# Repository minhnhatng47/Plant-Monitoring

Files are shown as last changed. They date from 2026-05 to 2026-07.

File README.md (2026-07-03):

# Plant-Monitoring-CPS

## Giới thiệu

**Plant-Monitoring-CPS** là mô hình hệ thống Cyber-Physical System (CPS) ứng dụng trong giám sát và chăm sóc cây trồng. Hệ thống tích hợp các công nghệ IoT, MQTT, Edge AI, cơ sở dữ liệu thời gian thực và mô hình Digital Twin trên Unity nhằm thu thập dữ liệu môi trường, xử lý tại biên, điều khiển thiết bị và trực quan hóa trạng thái cây trồng theo thời gian thực.

Đề tài được xây dựng cho mô hình chăm sóc rau cải mầm (*Brassica juncea*) trong môi trường thử nghiệm. Hệ thống có khả năng đo các thông số như nhiệt độ, độ ẩm không khí, độ ẩm đất và cường độ ánh sáng. Dữ liệu được gửi từ ESP32 về Raspberry Pi thông qua MQTT, sau đó được xử lý, lưu trữ, hiển thị trên Web Dashboard và đồng bộ với mô hình Digital Twin trong Unity.

## Mục tiêu dự án

Dự án hướng đến việc xây dựng một mô hình CPS hoàn chỉnh cho chăm sóc cây trồng thông minh với các mục tiêu chính:

- Thu thập dữ liệu môi trường từ các cảm biến.
- Truyền dữ liệu giữa ESP32, Raspberry Pi, Web Dashboard và Unity thông qua MQTT.
- Lưu trữ dữ liệu cảm biến theo thời gian thực bằng InfluxDB.
- Xử lý dữ liệu tại biên bằng Raspberry Pi.
- Ứng dụng mô hình Machine Learning để hỗ trợ quyết định bật/tắt bơm tưới.
- Điều khiển thiết bị chấp hành như relay, máy bơm và đèn.
- Xây dựng mô hình Digital Twin 3D trên Unity để mô phỏng trạng thái hệ thống.
- Hỗ trợ điều khiển hai chiều từ Web Dashboard và Unity xuống phần cứng thực tế.

## Kiến trúc hệ thống

Luồng hoạt động tổng quát của hệ thống:

```text
Cảm biến môi trường
        ↓
      ESP32
        ↓ MQTT
Raspberry Pi / MQTT Broker
        ↓
Edge Processing + AI Model
        ↓
InfluxDB + FastAPI Backend
        ↓
Web Dashboard / Unity Digital Twin
        ↓
Lệnh điều khiển thiết bị
        ↓
ESP32 → Relay → Bơm / Đèn
```

Trong đó:

- **ESP32** đọc dữ liệu cảm biến và điều khiển thiết bị chấp hành.
- **MQTT Broker Mosquitto** làm trung gian truyền nhận dữ liệu.
- **Raspberry Pi 4B** đóng vai trò Edge Gateway để xử lý dữ liệu, chạy AI và lưu trữ.
- **InfluxDB** lưu dữ liệu cảm biến dạng chuỗi thời gian.
- **FastAPI Backend** cung cấp API và WebSocket cho giao diện.
- **Web Dashboard** hiển thị dữ liệu và điều khiển thiết bị.
- **Unity Digital Twin** mô phỏng nhà kính, cây trồng và trạng thái thiết bị trong môi trường 3D.

## Chức năng chính

### 1. Giám sát dữ liệu môi trường

Hệ thống thu thập các thông số chính:

- Nhiệt độ không khí
- Độ ẩm không khí
- Độ ẩm đất
- Cường độ ánh sáng
- Trạng thái bơm
- Trạng thái đèn
- Trạng thái hệ thống

### 2. Truyền nhận dữ liệu MQTT

ESP32 publish dữ liệu cảm biến lên MQTT Broker. Raspberry Pi, Web Dashboard và Unity có thể subscribe các topic tương ứng để nhận dữ liệu realtime.

MQTT được sử dụng để:

- Gửi dữ liệu cảm biến từ ESP32 lên Raspberry Pi.
- Gửi lệnh điều khiển từ Raspberry Pi/Web/Unity xuống ESP32.
- Đồng bộ trạng thái thiết bị giữa phần cứng và giao diện.
- Kiểm tra khả năng truyền nhận dữ liệu hai chiều.

### 3. Edge AI trên Raspberry Pi

Raspberry Pi xử lý dữ liệu tại biên và chạy mô hình Machine Learning để hỗ trợ quyết định tưới nước. Mô hình AI sử dụng dữ liệu cảm biến để dự đoán trạng thái cần tưới hoặc không cần tưới.

Quy trình AI:

```text
Dữ liệu cảm biến → Tiền xử lý → Random Forest Model → Dự đoán trạng thái bơm → Gửi lệnh điều khiển
```

Mô hình chính được sử dụng:

- Random Forest

Các tiêu chí đánh giá:

- Accuracy
- Precision
- Recall
- F1-score
- Confusion Matrix
- Feature Importance

### 4. Điều khiển thiết bị

Hệ thống có thể điều khiển:

- Máy bơm nước
- Đèn chiếu sáng
- Relay
- Chức năng START hệ thống

Thiết bị có thể được điều khiển từ:

- Web Dashboard
- Unity Digital Twin
- Logic tự động từ AI
- Lệnh MQTT

### 5. Web Dashboard

Web Dashboard dùng để:

- Hiển thị dữ liệu cảm biến realtime.
- Theo dõi trạng thái bơm và đèn.
- Gửi lệnh điều khiển thiết bị.
- Quan sát lịch sử dữ liệu.
- Kiểm tra trạng thái hoạt động của hệ thống.

### 6. Unity Digital Twin

Unity Digital Twin mô phỏng hệ thống chăm sóc cây trồng trong môi trường 3D.

Các chức năng chính:

- Hiển thị mô hình nhà kính.
- Hiển thị dữ liệu cảm biến realtime.
- Hiển thị trạng thái bơm, đèn và cây trồng.
- Mô phỏng các giai đoạn phát triển của cây.
- Điều khiển thiết bị từ giao diện Unity.
- Đồng bộ trạng thái giữa mô hình số và hệ thống vật lý.

## Phần cứng sử dụng

| Thiết bị | Vai trò |
|---|---|
| ESP32 | Đọc cảm biến, gửi dữ liệu MQTT, điều khiển relay |
| Raspberry Pi 4B | Gateway xử lý biên, MQTT Broker, AI, lưu trữ dữ liệu |
| DHT11 | Đo nhiệt độ và độ ẩm không khí |
| Cảm biến độ ẩm đất | Đo độ ẩm đất |
| BH1750 | Đo cường độ ánh sáng |
| ADS1115 | Chuyển đổi tín hiệu analog sang digital |
| DS3231 | Cung cấp thời gian thực |
| Relay | Đóng/ngắt thiết bị chấp hành |
| Máy bơm mini | Tưới nước tự động |
| Đèn chiếu sáng | Bổ sung ánh sáng cho cây |
| Nguồn DC | Cấp nguồn cho hệ thống |

## Công nghệ sử dụng

| Thành phần | Công nghệ |
|---|---|
| Vi điều khiển | ESP32 |
| Gateway | Raspberry Pi 4B |
| Giao thức truyền thông | MQTT |
| MQTT Broker | Mosquitto |
| Backend | FastAPI |
| Database | InfluxDB |
| AI / Machine Learning | Python, Random Forest |
| Dashboard | Web Dashboard |
| Digital Twin | Unity |
| Dữ liệu huấn luyện | CSV |
| Ngôn ngữ lập trình | C/C++, Python, C#, JavaScript |

## Cấu trúc thư mục

```text
Plant-Monitoring/
│
├── BBB/
│   └── Xử lý biên, gateway hoặc các file liên quan đến Raspberry Pi
│
├── Hardware/
│   └── node_sensor/
│       └── Mã nguồn và thiết kế phần cảm biến
│
├── Web/
│   └── Giao diện Web Dashboard
│
├── esp32/
│   └── Firmware ESP32 đọc cảm biến và điều khiển thiết bị
│
├── Plant_DigitalTwin/
│   ├── Assets/
│   ├── Packages/
│   ├── ProjectSettings/
│   ├── file_csv/
│   ├── analyze_growth_from_old_csv.py
│   ├── analyze_plant_growth.py
│   └── generate_sample_csv.py
│
├── README.md
└── .gitignore
```

## Luồng dữ liệu hệ thống

1. ESP32 đọc dữ liệu từ cảm biến.
2. ESP32 đóng gói dữ liệu thành JSON.
3. ESP32 publish dữ liệu lên MQTT Broker.
4. Raspberry Pi subscribe dữ liệu từ MQTT Broker.
5. Raspberry Pi xử lý dữ liệu và lưu vào InfluxDB.
6. Mô hình AI dự đoán trạng thái cần tưới hoặc không cần tưới.
7. Raspberry Pi gửi lệnh điều khiển xuống ESP32 qua MQTT.
8. ESP32 điều khiển relay để bật/tắt bơm hoặc đèn.
9. Web Dashboard và Unity Digital Twin cập nhật trạng thái realtime.
10. Người dùng có thể điều khiển ngược lại từ Web hoặc Unity.

## Cài đặt và chạy hệ thống

### 1. Clone repository

```bash
git clone https://github.com/minhnhatng47/Plant-Monitoring.git
cd Plant-Monitoring
```

### 2. Cài đặt MQTT Broker trên Raspberry Pi

```bash
sudo apt update
sudo apt install mosquitto mosquitto-clients
sudo systemctl enable mosquitto
sudo systemctl start mosquitto
```

Kiểm tra trạng thái Mosquitto:

```bash
sudo systemctl status mosquitto
```

### 3. Chạy Backend / Gateway

Di chuyển vào thư mục chứa chương trình xử lý trên Raspberry Pi, sau đó cài các thư viện cần thiết:

```bash
pip install -r requirements.txt
```

Chạy chương trình:

```bash
python main.py
```

Lưu ý: tên file chạy thực tế có thể thay đổi tùy theo cấu trúc code trong thư mục gateway/backend.

### 4. Nạp code ESP32

Mở thư mục `esp32/` bằng Arduino IDE hoặc PlatformIO.

Cấu hình các thông tin cần thiết trong code:

```cpp
WiFi SSID
WiFi Password
MQTT Broker IP
MQTT Port
MQTT Topics
```

Sau đó nạp chương trình vào ESP32.

### 5. Chạy Web Dashboard

Mở thư mục `Web/`.

Nếu là web tĩnh, có thể mở trực tiếp:

```text
index.html
```

Nếu có server riêng, chạy theo file hướng dẫn hoặc file cấu hình trong thư mục `Web`.

### 6. Mở Unity Digital Twin

Mở Unity Hub, chọn thư mục:

```text
Plant_DigitalTwin/
```

Sau đó mở project bằng Unity.

Các thư mục quan trọng cần giữ nguyên:

```text
Assets/
Packages/
ProjectSettings/
```

Không nên xóa các file `.meta` trong project Unity vì Unity cần các file này để nhận diện asset.

## Dữ liệu AI

Dữ liệu huấn luyện AI được lưu dưới dạng CSV trong thư mục:

```text
Plant_DigitalTwin/file_csv/
```

Các script Python dùng để phân tích dữ liệu sinh trưởng:

```text
analyze_growth_from_old_csv.py
analyze_plant_growth.py
generate_sample_csv.py
```

Dữ liệu được sử dụng để:

- Kiểm tra dữ liệu thiếu.
- Phân tích đặc trưng đầu vào.
- Thống kê trạng thái bơm.
- Huấn luyện mô hình Random Forest.
- Đánh giá mô hình AI.
- Mô phỏng tăng trưởng cây trong Unity.

## Kết quả đạt được

Dự án đã xây dựng được mô hình CPS chăm sóc cây trồng gồm đầy đủ các thành phần:

- Phần cứng cảm biến và thiết bị chấp hành.
- Truyền nhận dữ liệu hai chiều qua MQTT.
- Lưu trữ dữ liệu cảm biến bằng InfluxDB.
- Điều khiển thiết bị từ Web Dashboard.
- Điều khiển thiết bị từ Unity Digital Twin.
- Huấn luyện mô hình Random Forest để hỗ trợ quyết định tưới.
- Mô phỏng trạng thái cây trồng và thiết bị trên Unity.
- Hiển thị dữ liệu realtime và trạng thái sinh trưởng của cây.

## Hạn chế

Một số hạn chế hiện tại của hệ thống:

- Mô hình mới triển khai ở quy mô thử nghiệm.
- Cảm biến sử dụng có độ chính xác phù hợp cho mô hình học tập, chưa phải thiết bị công nghiệp.
- AI chủ yếu tập trung vào quyết định bật/tắt bơm, chưa mở rộng sang nhận diện bệnh cây hoặc tối ưu đa mục tiêu.
- Digital Twin chủ yếu mô phỏng trạng thái và tăng trưởng cơ bản, chưa mô phỏng đầy đủ các quá trình sinh học phức tạp.
- Hệ thống chưa triển khai bảo mật nâng cao cho MQTT, API và dashboard.

## Hướng phát triển

Trong tương lai, hệ thống có thể được mở rộng theo các hướng:

- Bổ sung thêm cảm biến pH, EC, CO2 hoặc camera.
- Nâng cấp mô hình AI để dự đoán sinh trưởng cây trồng.
- Ứng dụng Computer Vision để nhận diện bệnh cây.
- Triển khai MQTT bảo mật bằng username/password hoặc TLS.
- Xây dựng dashboard hoàn chỉnh hơn với phân quyền người dùng.
- Đồng bộ dữ liệu lên cloud để theo dõi từ xa.
- Tối ưu mô hình Digital Twin để mô phỏng chính xác hơn.
- Triển khai hệ thống trên mô hình nhà kính quy mô lớn hơn.

## Thành viên nhóm

| STT | Họ và tên | MSSV |
|---|---|---|
| 1 | Lê Lữ Nhật An | 23139001 |
| 2 | Nguyễn Trần Minh Đức | 23139012 |
| 3 | Nguyễn Minh Nhật | 23139032 |
| 4 | Trà Hồng Phượng | 23139035 |
| 5 | Lê Đức Trí | 23139049 |

## Thông tin môn học

- Môn học: Hệ thống CPS
- Đề tài: Thiết kế và thi công mô hình hệ thống CPS tích hợp IoT, AI và Unity
- Giảng viên hướng dẫn: ThS. Trịnh Quốc Thanh
- Trường: Đại học Công nghệ Kỹ thuật TP. Hồ Chí Minh
- Khoa: Điện - Điện tử

## License

Dự án được thực hiện phục vụ mục đích học tập, nghiên cứu và thực nghiệm trong môn học Hệ thống CPS.

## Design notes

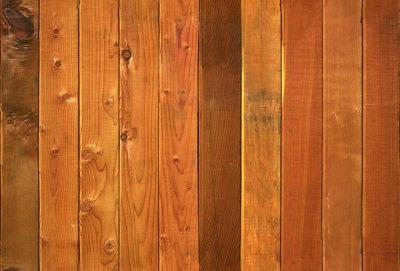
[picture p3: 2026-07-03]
Plant_DigitalTwin/Assets/Models/Greenhouse/model/Bois_3.jpg

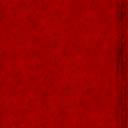
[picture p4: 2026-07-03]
Plant_DigitalTwin/Assets/Models/pipes_red/model/__Metal_Seamed__copy_0.jpg

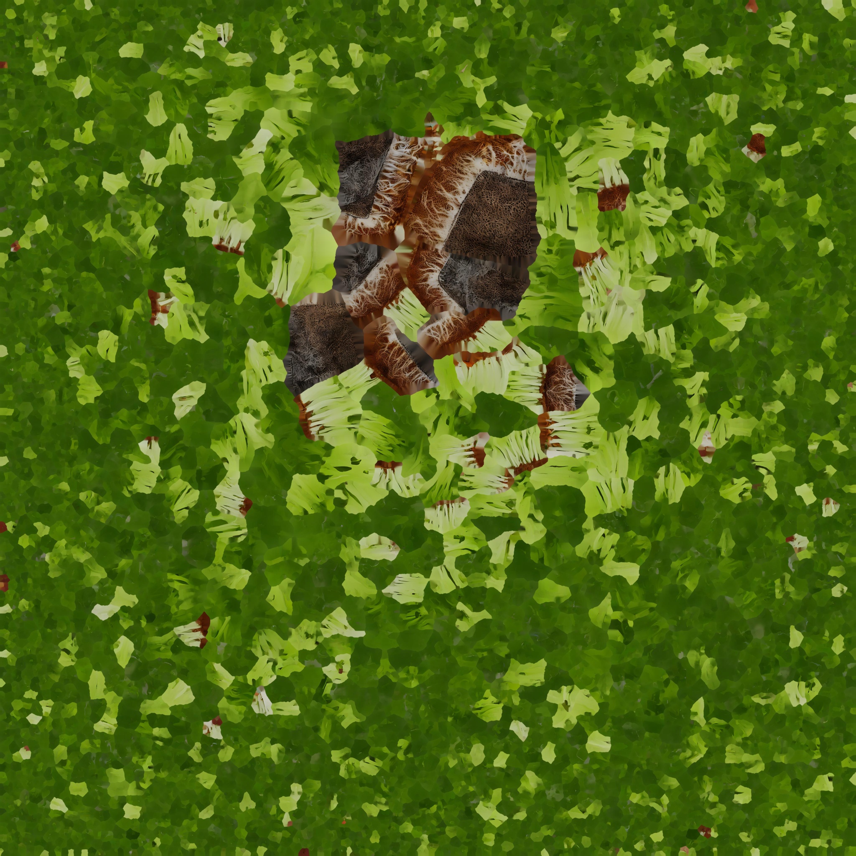
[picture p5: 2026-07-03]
Plant_DigitalTwin/Assets/Models/cay_cai_mam/tripo_convert_3a972f0b-5787-4fc4-a664-cabb3d16cb07.fbm/microgreensprouts3dmodel_basecolor.JPEG

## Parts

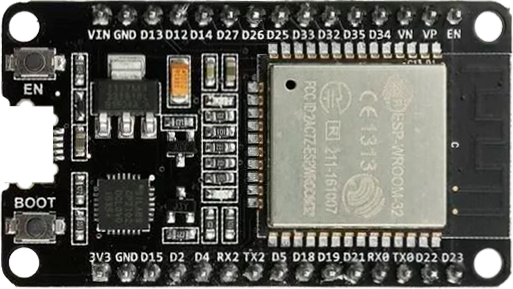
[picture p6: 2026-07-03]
Plant_DigitalTwin/Assets/Models/Asset PCB/esp-32D_HB/model/material_19.png

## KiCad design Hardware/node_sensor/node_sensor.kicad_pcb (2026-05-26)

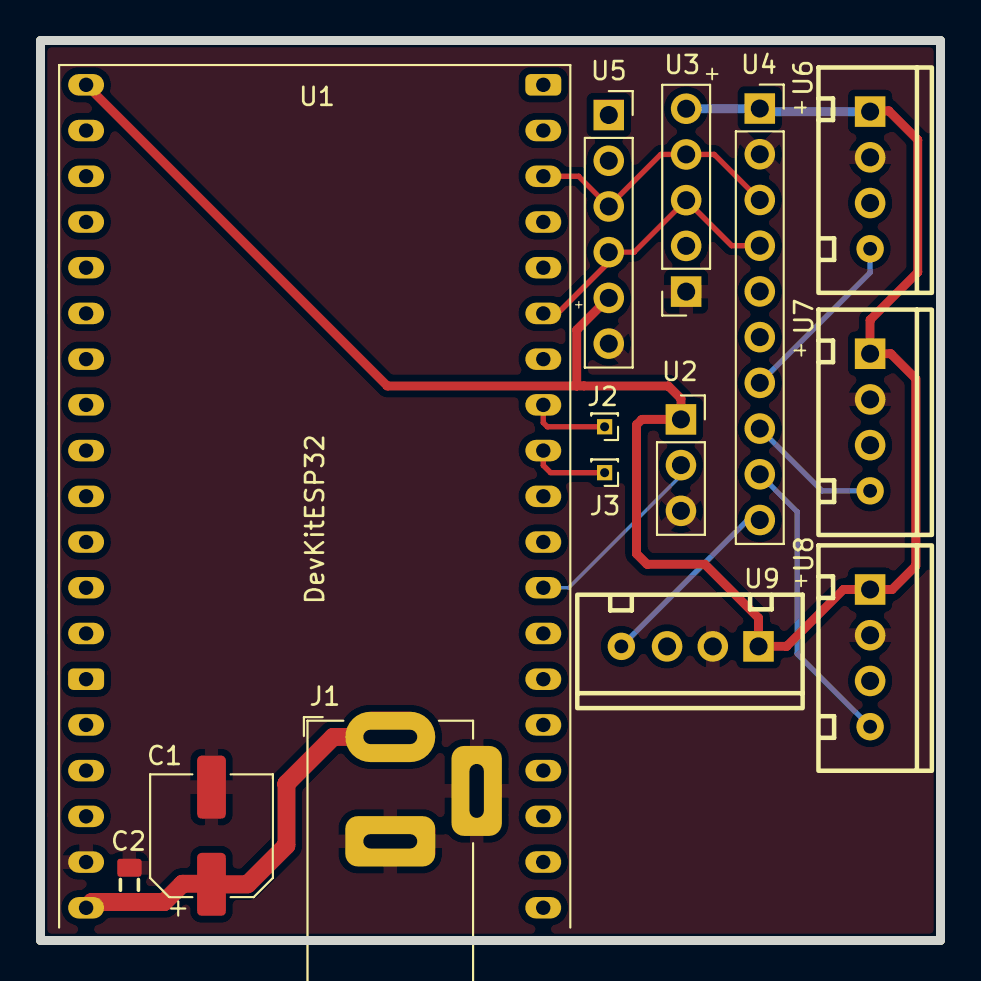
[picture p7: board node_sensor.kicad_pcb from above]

Board: 2 copper layers, 50.0 x 50.0 mm, 14 parts (0 on the bottom side), 12 nets.

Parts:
C1: 470uF; CP_Elec_6.3x7.7
C2: 0.1uF; C_0805
J1: Conn_Jack-DC; BarrelJack_Horizontal
J2: Pump; PinHeader_1x01_P1.00mm_Vertical
J3: Light; PinHeader_1x01_P1.00mm_Vertical
U1: DevKitESP32; ESP32-DevKitC
U2: DHT11; PinSocket_1x03_P2.54mm_Vertical
U3: BH1750; PinSocket_1x05_P2.54mm_Vertical
U4: ADS1115; PinSocket_1x10_P2.54mm_Vertical
U5: DS3231; PinSocket_1x06_P2.54mm_Vertical
U6, U7, U8, U9: Soil-Moisture; Conn_XH-P2.54mm-4P

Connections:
+3V3: U1.1 (3V), U2.1 (VCC), U3.5 (VCC), U4.1 (VCC), U5.5 (VCC), U6.1 (VCC), U7.1 (VCC), U8.1 (VCC), U9.1 (VCC)
+5V: C1.1, C2.1, J1.1, U1.19 (5V)
/1_wire: U1.27 (16), U2.2 (D0)
/I2C_SCL: U1.36 (22), U3.4 (SCL), U4.3 (SCL), U5.3 (SCL)
/I2C_SDA: U1.33 (21), U3.3 (SDA), U4.4 (SDA), U5.4 (SDA)
GND: C1.2, C2.2, J1.2, J1.3, U1.18 (GND), U2.3 (GND), U3.1 (GND), U4.2 (GND), U5.6 (GND), U6.2 (GND), U7.2 (GND), U8.2 (GND), U9.2 (GND)
unnamed: J2.1 (Pin_1_1), U1.31 (19)
unnamed: J3.1 (Pin_1_1), U1.30 (18)
unnamed: U4.7 (A0), U6.4 (A0)
unnamed: U4.8 (A1), U7.4 (A0)
unnamed: U4.9 (A2), U8.4 (A0)
unnamed: U4.10 (A3), U9.4 (A0)

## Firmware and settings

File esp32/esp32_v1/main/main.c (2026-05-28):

/**
 * @file main.c
 * @brief ESP32 Firmware v2.3 — Rau Cai Mam Brassica juncea Monitor (RTC Phase Owner)
 *
 * @details
 * - Sensors: DHT11 (Moving Average 5), BH1750, ADS1115 (4ch single-ended), DS3231 RTC
 * - Actuator: Pump relay (active HIGH, GPIO 26), Light relay (GPIO 27)
 * - Protocol: MQTT → BBB (topic: cps/greenhouse/sensors)
 * - Network: Tự động chuyển đổi giữa nhiều điểm truy cập WiFi (Multi-SSID) nếu rớt mạng.
 * - Resilience: Ring buffer 64 packets để lưu offline và tự động drain khi WiFi phục hồi.
 * - Phase owner: ESP32 đọc DS3231 RTC, tự tính Phase 1/2 theo planting_start_time,
 *   tự điều khiển đèn theo phase và gửi phase lên BBB.
 * - Time sync: WiFi có mạng -> NTP -> cập nhật DS3231 nếu lệch > 5 giây.
 */

#include <stdio.h>
#include <string.h>
#include <strings.h>
#include <stdlib.h>
#include <time.h>
#include <sys/time.h>

#include "freertos/FreeRTOS.h"
#include "freertos/task.h"
#include "freertos/event_groups.h"
#include "freertos/semphr.h"
#include "freertos/queue.h"

#include "esp_system.h"
#include "esp_wifi.h"
#include "esp_event.h"
#include "esp_netif.h"
#include "esp_sntp.h"
#include "esp_log.h"
#include "esp_timer.h"
#include "nvs_flash.h"
#include "nvs.h"
#include "driver/i2c_master.h"
#include "driver/gpio.h"
#include "mqtt_client.h"
#include "i2cdev.h"

#include <ads111x.h>
#include "bh1750.h"
#include "esp32-dht11.h"
#include "ds3231.h"

/* Compatibility: một số ESP-IDF dùng SNTP_OPMODE_POLL thay vì ESP_SNTP_OPMODE_POLL. */
#ifndef ESP_SNTP_OPMODE_POLL
#define ESP_SNTP_OPMODE_POLL SNTP_OPMODE_POLL
#endif

/* ================================================================
   CẤU HÌNH HỆ THỐNG WIIFI DẠNG MẢNG (MULTI-WIFI)
   ================================================================ */

/**
 * @brief Cấu trúc lưu trữ thông tin mạng WiFi
 */
typedef struct {
    const char *ssid;
    const char *password;
} wifi_cred_t;

/**
 * @brief Danh sách các mạng WiFi dự phòng. 
 * Hệ thống sẽ thử kết nối tuần tự từ trên xuống dưới.
 */
static const wifi_cred_t WIFI_NETWORKS[] = {
    {"Phòng toàn trai đẹp", "aicungdeptrai<3"},
    {"LUCAS",      "12345678"},
    {"Truong Lung",    "12345678"}
};
#define WIFI_NETWORK_COUNT (sizeof(WIFI_NETWORKS) / sizeof(wifi_cred_t))
#define WIFI_MAX_RETRY       3      /**< Số lần thử tối đa cho mỗi mạng trước khi đổi mạng khác */
#define WIFI_SCAN_MAX_AP     50     /**< Số AP tối đa lưu khi scan; tăng để tránh “quét thiếu mạng” */
#define WIFI_BOOT_WAIT_MS    30000  /**< Thời gian chờ WiFi lúc boot; không quá ngắn để tránh offline giả */
#define WIFI_SCAN_MIN_MS     250    /**< Active scan min time per channel */
#define WIFI_SCAN_MAX_MS     900    /**< Active scan max time per channel */

/* ================================================================
   CẤU HÌNH HỆ THỐNG KHÁC
   ================================================================ */

#define NODE_ID              "BRASSICA_JUNCEA_01"
#define PLANT_NAME           "Rau Cải Mầm (Brassica juncea)"
#define FW_VERSION           "2.7.0-rtc-nvs-phase-dt-stable"

/* MQTT */
#define MQTT_BROKER_URI      "mqtt://192.168.100.120"  /* IP hiện tại của BBB/Mosquitto */
#define MQTT_PORT            1883
#define MQTT_KEEPALIVE_S     60
#define MQTT_QOS             1
#define MQTT_CLIENT_ID       "esp32_brassica_01"

#define TOPIC_SENSOR         "cps/greenhouse/sensors"
#define TOPIC_STATUS         "cps/greenhouse/status"
#define TOPIC_ACTUATOR_STATE "cps/greenhouse/actuator/state"

/* BBB -> ESP32: luồng AUTO chính */
#define TOPIC_CMD_PUMP       "cps/greenhouse/cmd/pump"
#define TOPIC_CMD_LIGHT      "cps/greenhouse/cmd/light"      /* legacy/manual: chỉ log/ignore để tránh xung đột AUTO_RTC */
#define TOPIC_CMD_PLANTING_START "cps/greenhouse/cmd/planting_start"

/* BBB Influx Bridge -> ESP32: Digital Twin direct command */
#define TOPIC_DT_CMD_PUMP    "cps/greenhouse/dt/cmd/pump"
#define TOPIC_DT_CMD_LIGHT   "cps/greenhouse/dt/cmd/light"

/* GPIO & HW MUX */
#define I2C_MASTER_SDA       21
#define I2C_MASTER_SCL       22
#define I2C_MASTER_PORT      I2C_NUM_0

#define DHT11_GPIO           16
#define RELAY_PUMP_GPIO      26      /* Active HIGH */
#define RELAY_LIGHT_GPIO     27      /* Active HIGH */

/* ADS1115 Configuration */
#define ADS1115_I2C_ADDR     ADS111X_ADDR_GND   /* 0x48 */
#define SOIL_CH_COUNT        4
static const ads111x_mux_t SOIL_MUX[SOIL_CH_COUNT] = {
    ADS111X_MUX_0_GND,   /* AIN0 */
    ADS111X_MUX_1_GND,   /* AIN1 */
    ADS111X_MUX_2_GND,   /* AIN2 */
    ADS111X_MUX_3_GND,   /* AIN3 */
};

/* BH1750 */
#define BH1750_I2C_ADDR      BH1750_ADDR_LO     /* 0x23 */

/* Agronomic Parameters */
#define TEMP_IDEAL_MIN       18.0f
#define TEMP_IDEAL_MAX       24.0f
#define TEMP_GERM_IDEAL      22.0f
#define HUM_PHASE1_MIN       70.0f
#define HUM_PHASE1_MAX       85.0f
#define HUM_PHASE2_MIN       50.0f
#define HUM_PHASE2_MAX       65.0f
#define SOIL_IDEAL_MIN       55.0f
#define SOIL_IDEAL_MAX       80.0f
#define LIGHT_LEAK_THRESHOLD 150.0f  /* lux -- Phase 1 hộp xốp, không tối tuyệt đối */
#define LIGHT_PHASE2_MIN     150.0f  /* lux -- Đèn LED tối thiểu Phase 2 */
#define LIGHT_PHASE2_IDEAL   220.0f  /* lux -- Đèn LED tối ưu */

/* Timings */
#define SENSOR_READ_MS       5000
#define MQTT_PUBLISH_MS      5000
#define LIGHT_CTRL_MS        1000   /* Chu kỳ kiểm tra lịch đèn theo RTC */

/* NTP -> DS3231 RTC sync
 * DS3231 đang được dùng như đồng hồ local UTC+7 cho phase/light schedule.
 * Khi WiFi có Internet, ESP32 lấy giờ NTP, đổi sang UTC+7 rồi ghi vào DS3231 nếu sai lệch > 5s.
 */
#define NTP_SERVER_1              "pool.ntp.org"
#define NTP_SERVER_2              "time.google.com"
#define TZ_INFO_UTC7              "ICT-7"
#define NTP_SYNC_TIMEOUT_MS       30000
#define RTC_NTP_MAX_DRIFT_S       5
#define RTC_NTP_RETRY_MS          (10 * 60 * 1000)
#define RTC_NTP_SYNC_PERIOD_MS    (24 * 60 * 60 * 1000)

/* Local debug logs: hữu ích khi BBB/gateway chưa bật */
#define SENSOR_LOG_EVERY_N        1    /* 1 = log mỗi gói sensor, tương ứng ~5s */
#define LIGHT_LOG_HEARTBEAT_S     30   /* log trạng thái đèn mỗi 30s nếu không đổi */
#define OFFLINE_LOG_EVERY_N       5    /* khi MQTT mất, log buffer mỗi 5 packet */
#define DRAIN_MAX_PER_CYCLE       5    /* số packet offline đẩy lại mỗi chu kỳ publish */

/* Digital Twin direct safety timeout */
#define DT_PUMP_DEFAULT_DURATION_S   10
#define DT_PUMP_MAX_DURATION_S       15
#define DT_LIGHT_DEFAULT_DURATION_S  300
#define DT_LIGHT_MAX_DURATION_S      1800
#define ACTUATOR_STATE_PUBLISH_MS    5000

/* Phase & Light Schedule */
#define PHASE_1_DARK         1
#define PHASE_2_LIGHT        2
#define DEFAULT_PHASE        PHASE_1_DARK

/* Phase start policy
 * - Phase 0 ngâm hạt nằm ngoài firmware.
 * - planting_start_epoch = thời điểm đã gieo hạt vào đất.
 * - Lần đầu boot: sau khi kiểm tra RTC/NTP, nếu NVS chưa có mốc thì lưu RTC hiện tại vào NVS.
 * - Reset/mất điện/flash thường: NVS còn, không reset mốc.
 * - Bắt đầu lứa mới: gửi MQTT TOPIC_CMD_PLANTING_START action=SET_NOW/SET_EPOCH/CLEAR.
 */
#define DARK_PHASE_DAYS      2.0f
#define NVS_NS_PLANTING     "planting"
#define NVS_KEY_START_EPOCH "start_epoch"
#define NVS_KEY_LAST_CMD_ID "last_cmd"
#define PLANTING_CMD_ID_MAX 64

/* Task core pinning */
#define CORE_NET            0
#define CORE_APP            1

#define LIGHT_ON_HOUR_UTC7   8
#define LIGHT_OFF_HOUR_UTC7  17

/* ADS1115 Calibration */
#define SOIL_V_DRY           3.0f
#define SOIL_V_WET           1.1f

/* ================================================================
   BIẾN TOÀN CỤC & TẠO CẤU TRÚC DỮ LIỆU
   ================================================================ */

static const char *TAG = "SPROUT";

/* WiFi & MQTT States */
static EventGroupHandle_t s_wifi_eg;
#define WIFI_CONNECTED_BIT  BIT0
#define WIFI_FAIL_BIT       BIT1

static esp_mqtt_client_handle_t s_mqtt = NULL;
static bool s_mqtt_connected = false;

/* Biến phục vụ chức năng Multi-WiFi */
static int s_current_wifi_index = 0;
static int s_wifi_retry_count   = 0;

/* Các biến logic */
static int  s_step           = 0;
static int  s_current_phase  = DEFAULT_PHASE;   /* phase ESP32 tự tính từ RTC; dùng làm fallback nếu RTC lỗi */
static int64_t s_pump_direct_until_us  = 0;     /* Digital Twin direct pump hold-off */
static int64_t s_light_direct_until_us = 0;     /* Digital Twin direct light hold-off */
static SemaphoreHandle_t s_sensor_mutex;
static SemaphoreHandle_t s_i2c_mutex;
static i2c_dev_t         s_ads_dev = {0};
static i2c_dev_t         s_rtc_dev = {0};
static bool              s_sntp_started = false;
static time_t            s_planting_start_epoch = 0;
static bool              s_planting_start_valid = false;
static char              s_last_planting_cmd_id[PLANTING_CMD_ID_MAX] = {0};

/**
 * @brief Cấu trúc bản ghi chứa toàn bộ dữ liệu Snapshot từ cảm biến
 */
typedef struct {
    float temperature;
    float air_humidity;
    float soil_pct[SOIL_CH_COUNT];
    float lux;
    bool  pump_state;
    bool  light_state;
    int   phase;
    float days_after_planting;
    char  phase_source[24];    /* ESP32_RTC / RTC_ERROR */
    char  pump_mode[24];       /* AI_AUTO / DIRECT_DT */
    char  pump_reason[32];     /* BBB_AI_AUTO / DT_DIRECT / DIRECT_TIMEOUT_OFF */
    char  light_mode[24];      /* AUTO_RTC / DIRECT_DT / LEGACY_CMD */
    char  light_reason[32];    /* PHASE1_LOW_LIGHT / PHASE2_DAYLIGHT_SIM / DT_DIRECT */
    bool  dht11_ok;
    bool  bh1750_ok;
    bool  ads1115_ok;
    bool  rtc_ok;
    char  iso_time[32];     /* ISO8601 từ DS3231 */
    int   wifi_rssi;
    long  uptime_s;
} sensor_data_t;

static sensor_data_t g_sensor = {0};

/* ================================================================
   RING BUFFER - Tránh mất dữ liệu (Offline Storage)
   ================================================================ */

#define RING_BUF_SIZE        64     /* Số packet tối đa lưu khi offline */
#define JSON_MAX_LEN         1024

typedef struct {
    char  json[JSON_MAX_LEN];
    bool  valid;
} ring_entry_t;

typedef struct {
    ring_entry_t buf[RING_BUF_SIZE];
    int          head;    
    int          tail;    
    int          count;   
    SemaphoreHandle_t mutex;
} ring_buf_t;

static ring_buf_t s_ring = {0};

/**
 * @brief Khởi tạo Ring Buffer để lưu trữ JSON Payload khi mất mạng
 */
static void ring_init(void) {
    s_ring.head  = 0;
    s_ring.tail  = 0;
    s_ring.count = 0;
    s_ring.mutex = xSemaphoreCreateMutex();
}

/**
 * @brief Đẩy một MQTT payload vào bộ đệm
 * @param json Chuỗi JSON cần lưu
 * @return true nếu thành công, false nếu bộ đệm bận (mutex lock failed)
 */
static bool ring_push(const char *json) {
    if (!xSemaphoreTake(s_ring.mutex, pdMS_TO_TICKS(50))) return false;

    if (s_ring.count == RING_BUF_SIZE) {
        s_ring.tail = (s_ring.tail + 1) % RING_BUF_SIZE;
        s_ring.count--;
        ESP_LOGW("RING", "Buffer đầy — ghi đè packet cũ nhất. Gateway/MQTT broker có thể chưa bật");
    }

    strlcpy(s_ring.buf[s_ring.head].json, json, JSON_MAX_LEN);
    s_ring.buf[s_ring.head].valid = true;
    s_ring.head  = (s_ring.head + 1) % RING_BUF_SIZE;
    s_ring.count++;

    int count_after_push = s_ring.count;
    xSemaphoreGive(s_ring.mutex);

    if ((count_after_push % OFFLINE_LOG_EVERY_N) == 0 || count_after_push == 1 || count_after_push == RING_BUF_SIZE) {
        ESP_LOGW("RING", "Đang lưu offline: %d/%d packet", count_after_push, RING_BUF_SIZE);
    }
    return true;
}

static bool ring_peek(char *out_json) {
    if (!xSemaphoreTake(s_ring.mutex, pdMS_TO_TICKS(50))) return false;
    bool has = (s_ring.count > 0);
    if (has) strlcpy(out_json, s_ring.buf[s_ring.tail].json, JSON_MAX_LEN);
    xSemaphoreGive(s_ring.mutex);
    return has;
}

static void ring_pop(void) {
    if (!xSemaphoreTake(s_ring.mutex, pdMS_TO_TICKS(50))) return;
    if (s_ring.count > 0) {
        s_ring.buf[s_ring.tail].valid = false;
        s_ring.tail  = (s_ring.tail + 1) % RING_BUF_SIZE;
        s_ring.count--;
    }
    xSemaphoreGive(s_ring.mutex);
}

static int ring_count(void) {
    if (!xSemaphoreTake(s_ring.mutex, pdMS_TO_TICKS(50))) return 0;
    int c = s_ring.count;
    xSemaphoreGive(s_ring.mutex);
    return c;
}

/* ================================================================
   BỘ LỌC MOVING AVERAGE DHT11
   ================================================================ */

#define DHT_FILTER_SIZE 5

typedef struct {
    float temp_buf[DHT_FILTER_SIZE];
    float hum_buf[DHT_FILTER_SIZE];
    uint8_t index;
    uint8_t count;
} dht_filter_t;

static dht_filter_t s_dht_ma = {0};

static void dht11_moving_avg(float t, float h, float *out_t, float *out_h) {
    s_dht_ma.temp_buf[s_dht_ma.index] = t;
    s_dht_ma.hum_buf[s_dht_ma.index]  = h;
    s_dht_ma.index = (s_dht_ma.index + 1) % DHT_FILTER_SIZE;
    if (s_dht_ma.count < DHT_FILTER_SIZE) s_dht_ma.count++;

    float st = 0, sh = 0;
    for (int i = 0; i < s_dht_ma.count; i++) {
        st += s_dht_ma.temp_buf[i];
        sh += s_dht_ma.hum_buf[i];
    }
    *out_t = st / s_dht_ma.count;
    *out_h = sh / s_dht_ma.count;
}

/* ================================================================
   HELPER - RTC & CẢM BIẾN
   ================================================================ */

static bool i2c_take(uint32_t timeout_ms) {
    if (!s_i2c_mutex) return true;
    return xSemaphoreTake(s_i2c_mutex, pdMS_TO_TICKS(timeout_ms)) == pdTRUE;
}

static void i2c_give(void) {
    if (s_i2c_mutex) xSemaphoreGive(s_i2c_mutex);
}

static bool rtc_get_time_safe(struct tm *out) {
    if (!out) return false;
    bool ok = false;
    if (i2c_take(2500)) {
        ok = (ds3231_get_time(&s_rtc_dev, out) == ESP_OK);
        i2c_give();
    }
    return ok;
}

static bool rtc_set_time_safe(const struct tm *in) {
    if (!in) return false;
    struct tm tmp = *in;
    bool ok = false;
    if (i2c_take(2500)) {
        ok = (ds3231_set_time(&s_rtc_dev, &tmp) == ESP_OK);
        i2c_give();
    }
    return ok;
}

static time_t tm_local_to_epoch(struct tm t) {
    t.tm_isdst = -1;
    return mktime(&t);
}

static bool rtc_get_epoch_from_ds3231(time_t *epoch_out) {
    struct tm t = {0};
    if (!rtc_get_time_safe(&t) || t.tm_year <= 100) return false;
    time_t e = tm_local_to_epoch(t);
    if (e <= 0) return false;
    if (epoch_out) *epoch_out = e;
    return true;
}

static void epoch_to_local_tm(time_t epoch, struct tm *out) {
    localtime_r(&epoch, out);
}

static void epoch_to_iso_utc7(time_t epoch, char *buf, size_t len) {
    if (!buf || len == 0) return;
    if (epoch <= 0) {
        strlcpy(buf, "INVALID", len);
        return;
    }
    struct tm t = {0};
    epoch_to_local_tm(epoch, &t);
    strftime(buf, len, "%Y-%m-%dT%H:%M:%S+07:00", &t);
}

static bool planting_start_load_from_nvs(void) {
    nvs_handle_t h;
    int64_t epoch = 0;
    esp_err_t err = nvs_open(NVS_NS_PLANTING, NVS_READONLY, &h);
    if (err != ESP_OK) return false;

    err = nvs_get_i64(h, NVS_KEY_START_EPOCH, &epoch);

    size_t cmd_len = sizeof(s_last_planting_cmd_id);
    if (nvs_get_str(h, NVS_KEY_LAST_CMD_ID, s_last_planting_cmd_id, &cmd_len) != ESP_OK) {
        s_last_planting_cmd_id[0] = '\0';
    }

    nvs_close(h);

    if (err == ESP_OK && epoch > 0) {
        s_planting_start_epoch = (time_t)epoch;
        s_planting_start_valid = true;
        char iso[32];
        epoch_to_iso_utc7(s_planting_start_epoch, iso, sizeof(iso));
        ESP_LOGI(TAG, "PLANTING: load NVS start_epoch=%lld (%s), last_cmd=%s",
                 (long long)s_planting_start_epoch, iso,
                 s_last_planting_cmd_id[0] ? s_last_planting_cmd_id : "NONE");
        return true;
    }

    return false;
}

static bool planting_start_save_to_nvs(time_t epoch, const char *cmd_id) {
    if (epoch <= 0) return false;

    nvs_handle_t h;
    esp_err_t err = nvs_open(NVS_NS_PLANTING, NVS_READWRITE, &h);
    if (err != ESP_OK) {
        ESP_LOGE(TAG, "PLANTING: nvs_open write lỗi: %s", esp_err_to_name(err));
        return false;
    }

    err = nvs_set_i64(h, NVS_KEY_START_EPOCH, (int64_t)epoch);
    if (err == ESP_OK && cmd_id && cmd_id[0]) {
        err = nvs_set_str(h, NVS_KEY_LAST_CMD_ID, cmd_id);
    }
    if (err == ESP_OK) err = nvs_commit(h);
    nvs_close(h);

    if (err == ESP_OK) {
        s_planting_start_epoch = epoch;
        s_planting_start_valid = true;
        if (cmd_id && cmd_id[0]) strlcpy(s_last_planting_cmd_id, cmd_id, sizeof(s_last_planting_cmd_id));
        char iso[32];
        epoch_to_iso_utc7(epoch, iso, sizeof(iso));
        ESP_LOGW(TAG, "PLANTING: save NVS start_epoch=%lld (%s), cmd_id=%s",
                 (long long)epoch, iso, cmd_id && cmd_id[0] ? cmd_id : "BOOT_INIT");
        return true;
    }

    ESP_LOGE(TAG, "PLANTING: save NVS lỗi: %s", esp_err_to_name(err));
    return false;
}

static bool planting_start_clear_nvs(void) {
    nvs_handle_t h;
    esp_err_t err = nvs_open(NVS_NS_PLANTING, NVS_READWRITE, &h);
    if (err != ESP_OK) return false;

    nvs_erase_key(h, NVS_KEY_START_EPOCH);
    nvs_erase_key(h, NVS_KEY_LAST_CMD_ID);
    err = nvs_commit(h);
    nvs_close(h);

    s_planting_start_epoch = 0;
    s_planting_start_valid = false;
    s_last_planting_cmd_id[0] = '\0';

    return err == ESP_OK;
}

static void rtc_sync_compile_time(void) {
    struct tm t = {0};
    if (!rtc_get_time_safe(&t)) return;

    if (t.tm_year <= 100) {   
        struct tm ct = {0};
        strptime(__DATE__ " " __TIME__, "%b %d %Y %H:%M:%S", &ct);
        if (rtc_set_time_safe(&ct)) {
            ESP_LOGW("RTC", "Đồng bộ RTC từ compile time: %s %s", __DATE__, __TIME__);
        }
    }
}

/**
 * @brief Kiểm tra system time đã hợp lệ sau NTP chưa.
 */
static bool system_time_is_valid(void) {
    time_t now = 0;
    struct tm timeinfo = {0};
    time(&now);
    localtime_r(&now, &timeinfo);
    return (timeinfo.tm_year >= (2024 - 1900));
}

/**
 * @brief Khởi động SNTP một lần. Không gọi lại nhiều lần để tránh lỗi state.
 */
static void ntp_start_once(void) {
    if (s_sntp_started) return;

    setenv("TZ", TZ_INFO_UTC7, 1);
    tzset();

    ESP_LOGI("NTP", "SNTP init: server1=%s server2=%s timezone=%s", NTP_SERVER_1, NTP_SERVER_2, TZ_INFO_UTC7);
    esp_sntp_setoperatingmode(ESP_SNTP_OPMODE_POLL);
    esp_sntp_setservername(0, NTP_SERVER_1);
    esp_sntp_setservername(1, NTP_SERVER_2);
    esp_sntp_init();

    s_sntp_started = true;
}

/**
 * @brief Chờ NTP cập nhật system time.
 */
static bool ntp_wait_time_valid(uint32_t timeout_ms) {
    int waited_ms = 0;
    while (waited_ms < (int)timeout_ms) {
        if (system_time_is_valid()) {
            time_t now = 0;
            struct tm local = {0};
            time(&now);
            localtime_r(&now, &local);
            ESP_LOGI("NTP", "System time valid: %04d-%02d-%02d %02d:%02d:%02d UTC+7",
                     local.tm_year + 1900, local.tm_mon + 1, local.tm_mday,
                     local.tm_hour, local.tm_min, local.tm_sec);
            return true;
        }
        vTaskDelay(pdMS_TO_TICKS(500));
        waited_ms += 500;
    }
    ESP_LOGW("NTP", "Timeout chờ NTP sau %ums", timeout_ms);
    return false;
}
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
void app_main(void) {
    ESP_LOGI(TAG, "=== %s | %s v%s ===", PLANT_NAME, NODE_ID, FW_VERSION);
    ESP_LOGI(TAG, "MQTT broker=%s:%d | client_id=%s | sensor=%s | auto_pump=%s | dt_pump=%s | dt_light=%s | actuator_state=%s",
             MQTT_BROKER_URI, MQTT_PORT, MQTT_CLIENT_ID, TOPIC_SENSOR, TOPIC_CMD_PUMP,
             TOPIC_DT_CMD_PUMP, TOPIC_DT_CMD_LIGHT, TOPIC_ACTUATOR_STATE);
    ESP_LOGI(TAG, "Legacy topic %s is ignored; use %s for Digital Twin light direct",
             TOPIC_CMD_LIGHT, TOPIC_DT_CMD_LIGHT);
    ESP_LOGI(TAG, "Planting topic=%s | start=NVS after RTC/NTP check | dark_days=%.1f",
             TOPIC_CMD_PLANTING_START, DARK_PHASE_DAYS);

    esp_err_t nvs_ret = nvs_flash_init();
    if (nvs_ret == ESP_ERR_NVS_NO_FREE_PAGES || nvs_ret == ESP_ERR_NVS_NEW_VERSION_FOUND) {
        nvs_flash_erase();
        nvs_flash_init();
    }

    s_sensor_mutex = xSemaphoreCreateMutex();
    s_i2c_mutex = xSemaphoreCreateMutex();
    setenv("TZ", TZ_INFO_UTC7, 1);
    tzset();
    ring_init();
    hw_init();
    wifi_init();

    /* BOOT FLOW chuẩn:
     * 1) Nếu WiFi có IP thì check NTP và cập nhật DS3231 nếu lệch.
     * 2) Sau khi RTC đã được kiểm tra, load/create planting_start_epoch trong NVS.
     * 3) Task NTP sau đó chỉ sync DS3231 định kỳ, KHÔNG ghi lại mốc gieo.
     */
    EventBits_t boot_wifi_bits = xEventGroupGetBits(s_wifi_eg);
    if (boot_wifi_bits & WIFI_CONNECTED_BIT) {
        ntp_start_once();
        if (ntp_wait_time_valid(NTP_SYNC_TIMEOUT_MS)) {
            rtc_sync_from_ntp_if_needed();
        }
    } else {
        ESP_LOGW(TAG, "BOOT: chưa có WiFi, bỏ qua NTP ban đầu; dùng DS3231 hiện có để xét planting_start");
    }
    planting_start_init_from_nvs_or_rtc();

    mqtt_init();

    /* Core pinning:
     * CORE_NET: MQTT publish + NTP
     * CORE_APP: Sensor + RTC phase/light + actuator safety
     */
    xTaskCreatePinnedToCore(ntp_rtc_sync_task,   "ntp_rtc", 4096, NULL, 3, NULL, CORE_NET);
    xTaskCreatePinnedToCore(publish_task,        "publish",  4096, NULL, 3, NULL, CORE_NET);

    xTaskCreatePinnedToCore(sensor_task,         "sensor",   4096, NULL, 5, NULL, CORE_APP);
    xTaskCreatePinnedToCore(light_schedule_task, "light",    3072, NULL, 4, NULL, CORE_APP);
    xTaskCreatePinnedToCore(actuator_state_task, "act_state",4096, NULL, 4, NULL, CORE_APP);

    ESP_LOGI(TAG, "Tất cả tasks đã khởi động (RTC phase owner + Multi-WiFi + DT direct actuator)");
}

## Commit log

2026-05-18 upadted lib sensor
2026-05-18 updated driver + modified v6
2026-05-18 modified and tunned sensor
2026-05-23 updated esp32 v2
2026-05-24 changed phase awaness flow
    [node_sensor.kicad_pcb, node_sensor.kicad_sch]
2026-05-24 updated hardware + fixed conflict Gatway
    [node_sensor-B_Cu.gbr, node_sensor-B_Mask.gbr, node_sensor-B_Paste.gbr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]
2026-05-26 "updated topic DT in Unity"
    [node_sensor.kicad_pcb]
2026-05-26 updated flow DT
2026-05-27 updated nvs saved start timer
